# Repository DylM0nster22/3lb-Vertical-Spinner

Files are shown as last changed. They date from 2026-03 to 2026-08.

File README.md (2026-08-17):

### This is a 3lb Vertical spinner Combat robot.
The robot has a 5.2 inch weapon that runs on a 3d printed weapon hub that is belted to a 2812 brushless motor with a 2:1 ratio. The drive of the robot is direct driven on Repeat Robotics 2006 pros. 
All the parts are screws together using various length m4 plastite screws; you can find the lengths of them in the cad by checking the hole depth.
All the print settings for the front and back are in the BOM.
I really wanted to make this because my previous 3lb was a meltybrain which was a robot that was supposed to spin really fast and use its entire weight to do damage, but instead it spun slowly and just got beatup. This robot is my redemption, and in theory it will be really really strong

Here is a render of the main forked version 


And here is a render of the wedge config 


Here is a slightly jank wiring diagram

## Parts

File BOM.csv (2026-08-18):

Part | Weight | Quantity on bot | Quantity to buy/print | Total Weight | Cost | Material | Shipping | Total Cost With Spares | Provider | Link | Normal config | Wedge Config | Description | Subsystem
COMMON PARTS (BOTH CONFIGS) |  |  |  |  |  |  |  |  |  |  | FALSE | FALSE
Armor | 31.5 | 2 | 3 | 63 |  | UHMW |  | 0 | Amazon |  | TRUE | FALSE |  | Armor
Uprights | 41.25 | 2 | 3 | 82.5 |  | UHMW |  | 0 | Amazon |  | TRUE | TRUE |  | Chassis
Weapon stack hardware | 57 | 1 |  | 57 |  |  |  |  |  |  | TRUE | TRUE
Bottom lid | 62 | 1 | 1 | 62 | $19.95 | G10 |  | $19.95 | Amazon | https://www.amazon.com/Glass-Fiber-Sheet-335X300X4-0MM-Model/dp/B09QJYGCGV | TRUE | TRUE |  | Chassis
Top Lid | 43 | 1 | 1 | 43 | $15.95 | G10 |  | $15.95 | Amazon | https://www.amazon.com/cncarbonfiber-Fiberglass-Composite-inches-Models/dp/B09QJYR4CV | TRUE | TRUE |  | Chassis
Side rails | 22.2 | 2 | 3 | 44.4 |  | UHMW |  | 0 | Amazon |  | TRUE | TRUE | UHMW side rails | Chassis
Drive Motor | 64.5 | 2 | 2 | 129 | $55.00 | aluminium/steel |  | $110 | Repeat Robotics | https://repeat-robotics.com/products/repeat-drive-pro?variant=52037199364277 | TRUE | TRUE |  | Drive
Front Wheels | 21 | 2 | 3 | 42 | $0 | Vytaflex/TPU |  | 0 | 3D printed |  | TRUE | TRUE |  | Drive
Back Wheels | 21 | 2 | 3 | 42 | $0 | Vytaflex/TPU |  | 0 | 3D printed |  | TRUE | TRUE |  | Drive
Drive Belt | 2.5 | 2 | 4 | 5 | $2.42 | Rubber |  | $9.68 | Aliexpress | https://www.aliexpress.us/item/3256801542737589.html?scm_id=1007.40050.354490.0&scm-url=1007.40050.354490.0 | TRUE | TRUE | 204mm belt htd3m for the drive | Drive
All ESCs | 19 | 1 | 1 | 19 | $49.00 | PCB |  | $49.00 | Sequre | https://sequremall.com/products/sequre-blueson-a1-6s-8s-70a-4in1-esc?variant=44944132538556 | TRUE | TRUE |  | Electronics
battery | 62 | 2 | 2 | 124 | $28.73 | Lipo |  | $57.46 | Aliexpress | https://www.aliexpress.us/item/3256802945088264.html?mp=1 | TRUE | TRUE |  | Electronics
Power Switch | 2.15 | 1 | 1 | 2.15 | $9 | UHMW |  | $9.00 | Repeat Robotics | https://repeat-robotics.com/collections/beetleweight/products/fingertech-switch | TRUE | TRUE | Power switch for the robot | Electronics
Shaft collars | 1 | 2 | 1 | 2 | $9.99 | Aluminium |  | $9.99 | Amazon | https://www.amazon.com/Befenybay-Collar-Shaft-Screw-6mm-Silver/dp/B0B1C4XX65?s=industrial | TRUE | TRUE |  | Hardware
Drive motor spacers | 9 | 2 | 1 | 18 | $0.00 | TPU 1w 5% |  | $0.00 | 3D printed |  | TRUE | TRUE |  | Drive
Middle insert | 6 | 1 | 1 | 6 | $0 | TPU 2w 15% |  | 0 | 3D printed |  | TRUE | TRUE |  | Chassis
Drive Shafts | 3.1 | 2 | 1 | 6.2 | $10 | Aluminium |  | 10 | Repeat Robotics | https://repeat-robotics.com/products/repeat-drive-axle-mk2?variant=52037150998709 | TRUE | TRUE
Armor Standoffs | 2.4 | 4 | 1 | 9.6 | $4.36 | Aluminium |  | $4.36 | Aliexpress | https://www.aliexpress.us/item/3256801542737589.html?scm_id=1007.40050.354490.0&scm-url=1007.40050.354490.0 | TRUE | TRUE | 30mm deep blue | Hardware
Body Standoffs | 2.4 | 3 | 1 | 7.2 | $4.36 | Aluminium |  | $4.36 | Aliexpress | https://www.aliexpress.us/item/3256801542737589.html?scm_id=1007.40050.354490.0&scm-url=1007.40050.354490.0 | TRUE | TRUE | 30mm deep blue alu standoffs | Hardware
Weapon | 175 | 1 | 3 | 175 | $11.30 | 6.3mm AR500 |  | $33.90 | OSH cut | https://app.oshcut.com/cart | TRUE | TRUE |  | Weapon
Weapon pulley | 40 | 1 | 1 | 40 |  | PA6GF25 Solid |  | $0.00 | 3D printed |  | TRUE | TRUE |  | Weapon
Weapon motor pulley | 10 | 1 | 1 | 10 |  | PA6GF25 Solid |  | $0.00 | 3D printed |  | TRUE | TRUE |  | Weapon
Weapon Motor | 76 | 1 | 3 | 76 | $10.00 | Aluminium |  | $30.00 | Alibaba | https://www.alibaba.com/product-detail/MAD-BSC-2812-High-Performance-925_1601717627732.html | TRUE | TRUE |  | Weapon
Weapon belt | 8.815 | 1 | 3 | 8.815 | $3.18 | Rubber |  | $9.54 | Aliexpress | https://www.aliexpress.us/item/3256808473098612.html | TRUE | TRUE | 215mm belt htd5m for the weapon | Weapon
NORMAL CONFIGURATION ONLY |  |  |  |  |  |  |  |  |  |  | FALSE | FALSE
Screws | 70 | 1 | 1 | 70 |  |  |  | $0.00 |  |  | TRUE | FALSE
Back | 55 | 1 | 2 | 55 |  | TPU 2w 15% |  | $0.00 | 3D printed |  | TRUE | FALSE | 3dp TPU Back plate | Chassis
Front | 35 | 2 | 3 | 70 |  | TPU 5w 15% |  | $0.00 |  |  | TRUE | FALSE | 3dp TPU robot front | Chassis
Forks | 45 | 2 | 4 | 90 | $7.26 | 6.3mm AR500 |  | $29.02 | OSH cut | https://app.oshcut.com/cart | TRUE | FALSE | 6.3mm SR500 fork | Forks
WEDGE CONFIGURATION ONLY |  |  |  |  |  |  |  |  |  |  | FALSE | FALSE
Wedge Back | 34 | 1 | 2 | 34 |  | TPU 2w 15% |  | 0 | 3D printed |  | FALSE | TRUE |  | Wedge
Wedge Front | 61 | 2 | 2 | 122 |  | TPU 2w 15% |  | 0 | 3D printed |  | FALSE | TRUE |  | Wedge
Screws | 72 | 1 |  | 72 |  |  |  |  |  |  | FALSE | TRUE
Wedge armor | 14 | 2 |  | 28 |  | UHMW |  |  | Amazon |  | FALSE | TRUE
Wedge | 172 | 1 | 1 | 172 | $18.31 | 0.098" sr500 |  | $18.31 | OSH cut | https://app.oshcut.com/cart | FALSE | TRUE |  | Wedge
Under wedge plates | 8.5 | 1 | 1 | 8.5 |  |  |  | $0.00 |  |  | FALSE | TRUE
UNASSIGNED / SPARES |  |  |  |  |  |  |  |  |  |  | FALSE | FALSE
UHMW |  |  | 1 |  | $25.29 |  |  | $25.29 | Ebay | https://www.ebay.com/itm/376685243170?itmmeta=01KZWA3W3VA58E6T9NEGH3D6AD | FALSE | FALSE |  | Material
 |  |  |  |  |  |  |  |  |  |  | FALSE | FALSE
 |  |  |  |  |  |  |  |  |  |  | FALSE | FALSE
 |  |  |  |  |  |  |  |  |  |  | FALSE | FALSE
 |  |  |  | Normal config | Wedge Config | Total
 |  |  |  | 1358.865 | 1447.365 | HC Total
 |  |  |  | 1360.77711 | 1360.77711
 |  |  |  | 1.91211 | -86.58789
Weapon 18:32 htd5m
Drive htd3m
 |  |  |  | GRAND TOTAL | $445.81 | $69.50 | $515.31
 |  |  |  | Provider | Parts Cost | Shipping Cost+Tax | Total Cost
 |  |  |  | 3D printed | $0.00 | $0.00 | $0.00
 |  |  |  | Alibaba | $30.00 | $10.00 | $40.00
 |  |  |  | Aliexpress | $85.40 | $14.38 | $99.78 | ✔
 |  |  |  | Amazon | $45.89 | $3.33 | $49.22 | ✔
 |  |  |  | Ebay | $25.29 | $11.49 | $36.78 | ✔
 |  |  |  | OSH cut | $81.23 | $23.22 | $104.45 | ✔
 |  |  |  | Repeat Robotics | $129.00 | $5.00 | $134.00 | ✔
 |  |  |  | Sequre | $49.00 | $2.08 | $51.08 | ✔
 |  |  |  |  |  | Budget $400

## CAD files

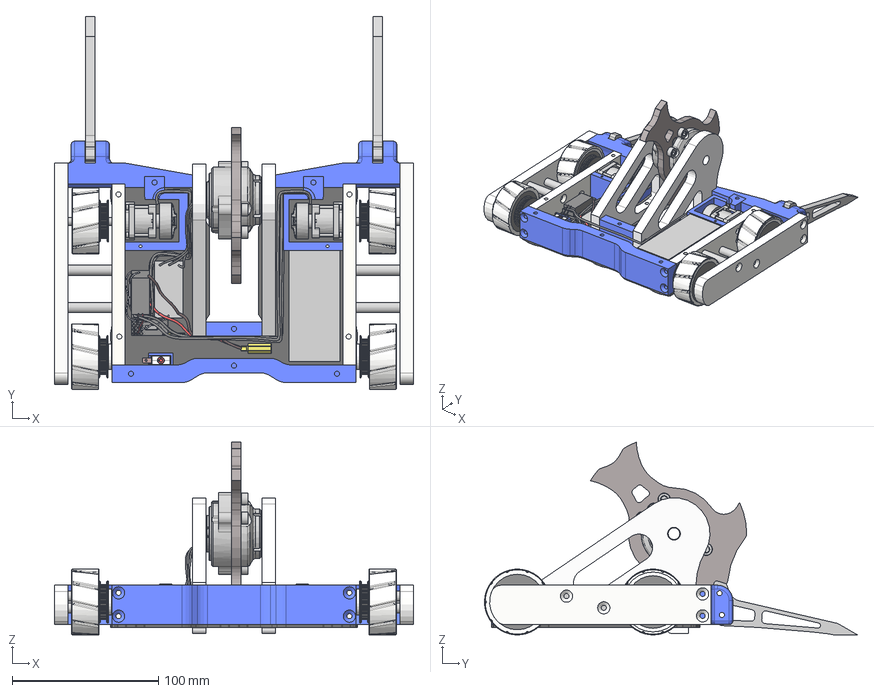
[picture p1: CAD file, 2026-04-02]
3lb.step
246.0 x 255.3 x 131.9 mm
M2812-1_Flat^M2812-MagRing_HUB-2812-V1.0(2)_HUB-2812-V1.0 x 2
M2812-2^M2812-MagRing_HUB-2812-V1.0(2)_HUB-2812-V1.0
M2812-4^M2812-MagRing_HUB-2812-V1.0(2)_HUB-2812-V1.0 x 14
6805_5972K216^HUB-2812-V1.0(2)_HUB-2812-V1.0
6000_5972K241^HUB-2812-V1.0(2)_HUB-2812-V1.0
M2812-6^HUB-2812-V1.0(2)_HUB-2812-V1.0
2812-HUB-001^HUB-2812-V1.0(2)_HUB-2812-V1.0
2812-HUB-002^HUB-2812-V1.0(2)_HUB-2812-V1.0
M3x4_91239A109^HUB-2812-V1.0(2)_HUB-2812-V1.0 x 2
M5x14_91290A230^HUB-2812-V1.0(2)_HUB-2812-V1.0 x 4
2812-HUB-005^HUB-2812-V1.0(2)_HUB-2812-V1.0
upright v2
Repeat Pro 2006
Middle
Bottom
Battery
Chassis
Drive Esc x 2
Receptor FS2A mini
Forks
Repeat Pro 2006_1
Standoffs (1)
RR-403-Mk1.0
91251A268_Black-Oxide Alloy Steel Socket Head Screw
RR-403-Mk1.0_1
91251A268_Black-Oxide Alloy Steel Socket Head Screw_1 x 2
Free spinning wheel_1
Free spinning wheel v4(Mirror)
switch half R1 x 2
copper tab_through hole
copper tab
SHCS 4-40x375_HX-SHCS 0.112-40x0.375x0
male connector

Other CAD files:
3lb.f3z

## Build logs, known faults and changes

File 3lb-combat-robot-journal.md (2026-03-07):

<!--
  This journal is auto generated by Hack Club Blueprint.
-->

# 2/7/2026 - Designed the Weapon and chose motor   

_Time spent: 1.0h_  

so far I designed the asymmetrical weapon with a long tooth and a small, wide counterweight. The diameter of the weapon is about 135mm, which is about as small as you want to make it for it to fit on the hub motor. This took me a bit because I also wanted it to look cool. As for the motor im going to use the Repeat Robotics hub motor, which is good because it's strong and makes the weapon system easier to manage, because instead of having to use belts, it just mounts onto the motor.
This is how the weapon looks 

# 2/18/2026 - Created a good base of the robot  

_Time spent: 6.0h_  

So far today, I have made the entire base for the robot and finalized what parts I'm going to use. For the weapon motor, I chose the Repeat Robotics 3lb hub motor, and for the drive, I chose the Repeat Robotics Pro 2006 motors. The robot is going to be controlled with a fs-i6 remote, which I already have, and a fs2a drone receiver, which only weighs about 1g, so it's perfect. The Escs im going to use to control the drive motors are 40A AM32 ESCs, which are from Aliexpress, and for the weapon im going to use a 90A ESC from MEPSKING. For the battery, I decided on using a GNB 1100mah 4s lihv which is good because it has a high discharge rate. As for the robot, it took me a few redesigns to choose a shape I like, but I ended up with a rectangle that's wider than it is long, and it's going to be 3d printed out of TPU. 

For the upright they are going to be made out of UHMW, which is slightly pocketed to save on weight.


The top lid is going to be made out of 1.5mm tegris, and if that's not strong enough im going to double it up and run two of them if I have weight. The bottom lid is going to be cut by robotsmashingleauge out of 2mm thick carbon fiber because of its stiffness and strength. The wheels are going to be made out of tpu and for grip their going to use Vytaflex. The wheels are going to be belted from the front to the back to have 4wd.

This is the current state of the robot 



# 2/22/2026 - Remade the body and got closer to finishing   

_Time spent: 5.0h_  

Over the past few days, when I worked on this i kept forgetting to journal, I remade the body, made armor, made forks, added screw holes to everything, and remade the wheels. This is how the body looks now  The white side rails will be made out of UHMW, the same material as my uprights, because it is light and strong. The blue parts are going to be made out of solid TPU. The UHMW parts are mounted from the front, back, top, and bottom, so there is a lot of support. The front parts are mounted to the UHMW, the uprights, and the top and bottom. The back piece is mounted with three holes in the top and bottom and is attached to the UHMW. The uprights are the same but I actually added the mounting holes now. The reason for the changes are because when i showed my friends they pointed out a bunch of issues with it.
here is a front view 
here is a side view 
and here is a top view 
I also had to add larger holes to the cf so it could be passthrough holes 
The forks on the front are going to be made out of 6.3mm thick ar500 steel

# 3/4/2026 - Made my horizontal config   

_Time spent: 9.0h_  

Over the past few days ive been having trouble making a horizontal config. The way horizontal configs work usually is you have a wedge in the front, which replaces the forks, and it is normally made out of 1.6mm titanium, and it deflects the hits from horizontals and makes them bounce off or go flying instead of them digging into your bot. When I made my original wedge, it looked like this  which is super cool because it would protect my uprights and body at the same time butttt it was 130$ out of ti which was way too much. So I made a steel wedge instead, which only costs 35$ for 2 wedges and an extra side piece. 
Because of how heavy steel is i had to make a bunch of compromises like removing side armor when I have it on and using a smaller weapon and uprights, but I only have to use those when I fight a horizotal otherwise, I get to run it as you saw before. To mount the wedge, I had to make these, which will have screw holes for the wedge to hold onto 
The new version of the uprights and weapon looks like this 
The full wedge version of the robot will look like this 

# 3/5/2026 - Fixed the CF and made finishing touches  

_Time spent: 2.5h_  

Today I asked my friend to look over my bot and the biggest thing he said was a issue was the carbon fiber, the issue was that all the screw holes were too close to the edge and it would have just ripped out so he had me fix all of those. The other issue was the UHMW side armor this was a small issue and it was just rounding the armor to be around the wheel instead of a block.
This is how my top lid looks now 

And this is how the bottom lid looks 

I also fixed the motor spacer to included the weapon motor wires and the routing of the drive motor wires


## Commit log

2026-03-07 Added CAD with Timeline
2026-03-07 Added .step
    [3lb.step]
2026-03-07 Replace wiring diagram image with updated version
    Updated wiring diagram image with a new source.
2026-03-07 Modify Beetle parts list and update totals
    Updated the item list with new entries and adjusted totals.
    [Beetle - Sheet1.csv]
2026-03-07 Update Beetle part list with new entries and costs
    [Beetle - Sheet1.csv]
2026-04-02 added new cad files
    [3lb.step]
2026-08-18 Rename Untitled spreadsheet - Beetle - Sheet1 (1) (2).csv to BOM.csv
    [BOM.csv]
2026-08-18 add new models
    [3lb.f3z]
2026-10-15 Add 3dp parts and laser cut parts
2026-10-27 Revise wiring diagram and update image source
    Updated wiring diagram image and improved description.
2026-10-27 Update wiring diagram image in README
    Updated wiring diagram image with a new source URL and dimensions.
